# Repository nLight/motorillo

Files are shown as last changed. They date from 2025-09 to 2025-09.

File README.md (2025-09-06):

# Motorillo 🎬

> **Precision stepper motor controller with WebUSB interface for camera sliders, timelapses, and automation projects.**





## ✨ Features

- 🌐 **Browser Control**: Direct WebUSB communication - no drivers needed
- 📱 **Dual Interface**: Standalone OLED menu + web interface
- 💾 **Persistent Storage**: Save up to 5 programs in EEPROM
- ⚡ **Precision Control**: Customizable speed (1ms to 4.3M ms per step)
- 🔄 **Auto-Recovery**: Graceful USB disconnection handling
- 🎯 **Infinite Programs**: Forward/backward motion until manually stopped
- 📊 **Real-time Feedback**: Live position and status updates

## 🚀 Quick Start

### Hardware Requirements

| Component | Specification |
| --- | --- |
| **Arduino Board**  | Leonardo/Micro/Zero (WebUSB compatible) |
| **Stepper Motor**  | 200 steps/revolution with compatible driver |
| **Driver** | A4988, TMC2209 |
| **Display** | SSD1306 OLED 96×16 pixels (I2C) |
| **Control Button** | Momentary push button |

### Connections

```
Arduino Leonardo/Micro:
├── Pin 10 → Stepper DIR
├── Pin 16 → Stepper STEP
├── Pin 2  → Control Button (internal pullup)
├── SDA/SCL → OLED Display (I2C)
└── USB → Computer (WebUSB + Power)
```

### Installation

1. **Clone the repository:**

   ```bash
   git clone https://github.com/yourusername/motorillo.git
   cd motorillo
   ```

2. **Upload firmware:**

   - Open `steppper.ino` in Arduino IDE
   - Install required libraries (see [Setup Guide](docs/setup/installation.md))
   - Upload to your Arduino board

3. **Access web interface:**
   - Serve the `webusb/` folder on localhost
   - Connect via Chrome/Edge browser
   - Click "Connect Slider" to establish WebUSB connection

## 📖 Documentation

- 📋 **[Setup Guide](docs/setup/)** - Hardware assembly and software installation
- 🛠 **[User Manual](docs/features/)** - Operating modes and program creation
- 👨‍💻 **[Development](docs/development/)** - Architecture and API reference
- 🔧 **[Troubleshooting](docs/setup/troubleshooting.md)** - Common issues and solutions

## 💡 Use Cases

- **📹 Camera Sliders**: Smooth motion for video production
- **⏱ Timelapse Photography**: Ultra-slow motion over hours/days
- **🏭 Automation**: Precise positioning for manufacturing
- **🎓 Education**: Learn motor control and WebUSB programming
- **🔬 Research**: Laboratory positioning systems

## 🎮 Control Modes

### Standalone Mode (OLED + Button)

- Navigate stored programs with push button
- View current position and status
- Start/stop/pause program execution

### WebUSB Mode (Browser Interface)

- Create and save motion programs
- Manual jog controls with custom speed
- Real-time monitoring and control
- Bulk program management

## 🔧 Technical Specifications

| Parameter | Range | Default |
| --- | --- | --- |
| **Speed Range** | 1ms - 4,294,967,295ms per step  | 1000ms |
| **Max Programs** | 5 stored programs | - |
| **Position Range** | 0 - 65,535 steps | 2000 steps |
| **Loop Programs**  | Infinite until manually stopped | - |
| **Memory Usage** | ~1KB EEPROM | - |

## 🏗 Architecture

```
┌─────────────────┐    ┌──────────────────┐
│   Web Browser   │◄──►│   Pro Micro      │
│   (WebUSB UI)   │    │   (Motorillo)    │
└─────────────────┘    └──────────────────┘
                                │
                        ┌───────┴───────┐
                        │ Stepper Motor │
                        │   + Driver    │
                        └───────────────┘
```

**Modular Firmware:**

- `motor_control` - Movement and positioning
- `command_processor` - WebUSB communication
- `config_manager` - EEPROM storage
- `display_manager` - OLED interface
- `menu_system` - Standalone navigation

## 🤝 Contributing

We welcome contributions! Please see our [Development Guide](docs/development/) for:

- Code architecture overview
- Building and testing procedures
- Pull request guidelines

## 📚 Complete Documentation

This README provides a quick overview. For comprehensive documentation:

- **[Setup & Installation](docs/setup/)** - Hardware wiring, software installation, troubleshooting
- **[Features & Usage](docs/features/)** - User manual, speed control, WebUSB features
- **[Development](docs/development/)** - Architecture, API reference, protocol details

Start with the [Documentation Index](docs/README.md) for easy navigation.

## 📄 License

This project is licensed under the MIT License - see the [LICENSE](LICENSE) file for details.

## 🙏 Acknowledgments

- Built with Arduino framework and WebUSB standard
- OLED support via Adafruit libraries
- Inspired by the maker community's creativity

---

**Ready to automate your motion?** [Get started with the setup guide](docs/setup/) →

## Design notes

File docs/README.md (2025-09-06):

# Motorillo Documentation

Welcome to the comprehensive documentation for Motorillo, the precision stepper motor controller with WebUSB interface.

## 📖 Documentation Structure

### 🚀 Setup & Installation

Get Motorillo up and running on your system.

- **[Installation Guide](setup/installation.md)** - Complete setup from hardware to software
- **[Troubleshooting Guide](setup/troubleshooting.md)** - Common issues and solutions

### ✨ Features & Usage

Learn how to use all of Motorillo's capabilities.

- **[User Manual](features/user-manual.md)** - Complete operating guide for all users
- **[Manual Velocity Control](features/manual-velocity-control.md)** - Custom speed control system
- **[WebUSB Connection Management](features/webusb-connection.md)** - Connection handling and recovery
- **[Home Positioning System](features/home-positioning.md)** - Reference point management
- **[Extended Speed Range](features/extended-speed-range.md)** - Millisecond precision timing

### 👨‍💻 Development & Technical

Technical documentation for developers and advanced users.

- **[Architecture Overview](development/architecture.md)** - System design and module organization
- **[Command Protocol](development/command-protocol.md)** - Simplified WebUSB protocol design
- **[API Reference](development/api-reference.md)** - Complete WebUSB command reference

## 🎯 Quick Navigation

### New Users

1. Start with the **[Installation Guide](setup/installation.md)** to set up hardware and software
2. Read the **[User Manual](features/user-manual.md)** to learn basic operations
3. Check **[Troubleshooting](setup/troubleshooting.md)** if you encounter issues

### Existing Users

- **[Features Documentation](features/)** - Learn about specific capabilities
- **[API Reference](development/api-reference.md)** - WebUSB command protocol details
- **[Troubleshooting](setup/troubleshooting.md)** - Solutions to common problems

### Developers

1. **[Architecture](development/architecture.md)** - Understand the system design
2. **[Command Protocol](development/command-protocol.md)** - WebUSB communication protocol
3. **[API Reference](development/api-reference.md)** - Complete command reference

## 📋 Feature Overview

### Core Capabilities

- 🌐 **Browser Control**: Direct WebUSB communication - no drivers needed
- 📱 **Dual Interface**: Standalone OLED menu + web interface
- 💾 **Persistent Storage**: Save up to 5 programs in Arduino EEPROM
- ⚡ **Precision Control**: 1ms to 49+ days per step timing range
- 🔄 **Auto-Recovery**: Graceful USB disconnection handling

### Applications

- **📹 Camera Sliders**: Smooth motion for video production
- **⏱ Timelapse Photography**: Ultra-slow motion over hours/days
- **🏭 Automation**: Precise positioning for manufacturing
- **🎓 Education**: Learn motor control and WebUSB programming
- **🔬 Research**: Laboratory positioning systems

## 🛠 Technical Specifications

| Parameter | Range | Notes |
| --- | --- | --- |
| **Speed Range** | 1ms - 4.3B ms per step | ~49.7 days maximum |
| **Position Range** | 0 - 65,535 steps | 16-bit resolution |
| **Programs** | 5 stored programs | Persistent in EEPROM |
| **Cycle Count** | 1 - 255 cycles | For loop programs |
| **WebUSB** | Chrome/Edge browsers | No driver installation |

## 🔗 External Resources

- **[Arduino WebUSB Library](https://github.com/webusb/arduino)** - WebUSB implementation
- **[Adafruit SSD1306](https://github.com/adafruit/Adafruit_SSD1306)** - OLED display library
- **[WebUSB Specification](https://webusb.github.io/webusb/)** - WebUSB standard documentation

## 🤝 Contributing

We welcome contributions to both code and documentation!

**For Documentation**:

- Clear, concise writing
- Practical examples and use cases
- Screenshots and diagrams where helpful
- Cross-references between related topics

**For Code**:

- Follow existing code style and patterns
- Add documentation for new features
- Test thoroughly on Arduino hardware
- Consider memory constraints (Arduino Uno: 32KB flash, 2KB RAM)

## 📄 License

This documentation is part of the Motorillo project, licensed under the MIT License. See the main [LICENSE](../LICENSE) file for details.

---

**Need Help?** Start with the [Installation Guide](setup/installation.md) or check [Troubleshooting](setup/troubleshooting.md) for common issues.

**Ready to Develop?** Begin with the [Architecture Overview](development/architecture.md) to understand the system design.

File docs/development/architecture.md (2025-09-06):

# Motorillo Architecture Overview

This document provides a comprehensive overview of Motorillo's software architecture, design patterns, and module organization.

## System Architecture

### High-Level Design

```
┌─────────────────────────────────────────────────────────────┐
│                    USER INTERFACES                          │
├──────────────────┬──────────────────────────────────────────┤
│   Web Browser    │            OLED + Button                 │
│   (WebUSB Mode)  │         (Standalone Mode)                │
├──────────────────┴──────────────────────────────────────────┤
│                 COMMUNICATION LAYER                         │
├─────────────────────────────────────────────────────────────┤
│                 COMMAND PROCESSOR                           │
├─────────────────────────────────────────────────────────────┤
│                    CORE MODULES                             │
├─────────┬─────────┬─────────┬─────────┬───────────────────────┤
│ Motor   │ Display │  Menu   │ Config  │      EEPROM          │
│ Control │ Manager │ System  │ Manager │     Storage          │
└─────────┴─────────┴─────────┴─────────┴───────────────────────┘
```

### Modular Design Principles

**Separation of Concerns**: Each module handles a specific aspect of functionality

- **Motor Control**: Step generation, positioning, movement timing
- **Display Management**: OLED output, status display, menu rendering
- **Menu System**: Navigation, user interaction, program selection
- **Configuration**: Settings storage, EEPROM management, data persistence
- **Communication**: WebUSB protocol, command parsing, response handling

**Loose Coupling**: Modules communicate through well-defined interfaces

- Clear function signatures with minimal dependencies
- Event-driven communication where appropriate
- Shared state management through controlled interfaces

## Core Modules

### Motor Control (`src/motor_control.h/cpp`)

**Responsibilities**:

- Stepper motor step generation
- Position tracking and management
- Speed control and timing
- Movement execution and coordination

**Key Functions**:

```cpp
void setupMotorPins();                           // Initialize hardware pins
void moveToPositionWithSpeed(uint16_t pos, uint32_t speedMs);
void executeStoredProgram();                     // Run saved motion sequences
void updateMotorStatus();                        // Position tracking
```

**State Management**:

```cpp
extern long currentPosition;      // Current motor position
extern bool programRunning;       // Program execution state
extern bool programPaused;        // Pause state
```

**Design Patterns**:

- **State Machine**: Program execution states (stopped/running/paused)
- **Command Pattern**: Movement commands with parameters
- **Template Method**: Common movement logic with variable timing

### Display Manager (`src/display_manager.h/cpp`)

**Responsibilities**:

- OLED display initialization and control
- Status information rendering
- Menu display formatting
- Message display with timing

**Key Functions**:

```cpp
void setupDisplay();                             // Hardware initialization
void updateDisplay();                           // Refresh display content
void displayMessage(const char* msg, int duration);
void displayMenuItems(int selectedIndex);       // Menu rendering
```

**Display States**:

```cpp
extern unsigned long lastDisplayUpdate;         // Update timing
extern const unsigned long DISPLAY_UPDATE_INTERVAL;
```

**Design Patterns**:

- **Observer Pattern**: Display updates based on state changes
- **Composite Pattern**: Complex display layouts from simple elements
- **Strategy Pattern**: Different display modes (menu/status/message)

### Menu System (`src/menu_system.h/cpp`)

**Responsibilities**:

- Button input handling and debouncing
- Menu navigation logic
- Program selection and execution
- Mode switching (menu ↔ program execution)

**Key Functions**:

```cpp
void setupButton();                             // Input initialization
void checkButton();                            // Input processing with debouncing
void buildMenuItems();                         // Dynamic menu construction
void enterMenuMode();                          // Mode switching
void exitMenuMode();
```

**State Variables**:

```cpp
extern bool inMenuMode;                        // Current interface mode
extern int selectedMenuItem;                   // Navigation state
extern unsigned long lastButtonPress;         // Debouncing timing
```

**Design Patterns**:

- **State Machine**: Menu navigation states
- **Command Pattern**: Menu actions trigger operations
- **Builder Pattern**: Dynamic menu construction based on stored programs

### Configuration Manager (`src/config_manager.h/cpp`)

**Responsibilities**:

- EEPROM data organization and access
- Program storage and retrieval (loop and complex programs)
- Configuration persistence
- Data validation and integrity

**Key Functions**:

```cpp
void loadConfig();                             // System settings
void saveConfig();
bool loadLoopProgram(uint8_t id, LoopProgram* prog);
bool saveLoopProgram(uint8_t id, const LoopProgram* prog);
void loadProgramName(uint8_t id, char* name);
uint8_t getProgramType(uint8_t id);           // Program type detection
```

**Data Structures**:

```cpp
struct LoopProgram {
  uint16_t steps;     // Steps per direction
  uint32_t delayMs;   // Delay between steps
  uint8_t cycles;     // Number of cycles
};

struct ComplexProgram {
  uint8_t stepCount;
  struct {
    uint16_t position;
    uint32_t speedMs;
    uint16_t pauseMs;
  } steps[MAX_COMPLEX_STEPS];
};
```

**Design Patterns**:

- **Repository Pattern**: Abstract EEPROM access
- **Factory Pattern**: Program creation based on type
- **Memento Pattern**: State persistence and restoration

### Command Processor (`src/command_processor.h/cpp`)

**Responsibilities**:

- WebUSB communication protocol handling
- Binary command parsing and validation
- Response generation and transmission
- Error handling and logging

**Key Functions**:

```cpp
void processCommandCode(uint8_t cmdCode, char* data, int dataLen);
void sendProgramData();                        // Bulk data transmission
void handleConfigCommand(const uint8_t* data); // Configuration updates
void handleProgramCommand(const uint8_t* data); // Program management
```

**Protocol Design**:

```cpp
// Command structure
enum CommandCodes {
  CMD_CONFIG = 1,           // System configuration
  CMD_POS_WITH_SPEED = 15,  // Position movement
  CMD_LOOP_PROGRAM = 9,     // Simple programs
  CMD_PROGRAM = 10,         // Complex programs
  CMD_GET_ALL_DATA = 13,    // Data synchronization
  CMD_DEBUG_INFO = 14       // Connection health
};
```

**Design Patterns**:

- **Command Pattern**: Each command encapsulates operation
- **Strategy Pattern**: Different parsing strategies for command types
- **Chain of Responsibility**: Command processing pipeline

## Communication Architecture

### WebUSB Protocol Design

**Binary Format Benefits**:

- Memory efficiency (crucial for Arduino constraints)
- Fast parsing (no string manipulation overhead)
- Type safety (fixed-size fields prevent errors)
- Cross-platform compatibility (little-endian encoding)

**Protocol Stack**:

```
Application Layer  │ Movement Commands, Program Data
─────────────────  ├─────────────────────────────────
Transport Layer    │ Binary Protocol, Command Codes
─────────────────  ├─────────────────────────────────
Physical Layer     │ WebUSB, Arduino USB Stack
```

**Data Flow**:

```
Browser JavaScript ──[Binary Commands]──→ Arduino
                  ←──[Status/Data]───────
```

### Connection Management

**State Machine**:

```
┌─────────────┐    WebUSB Available    ┌──────────────────┐
│ Standalone  │ ───────────────────→   │ Programming Mode │
│    Mode     │ ←─────────────────────  │                  │
└─────────────┘    Connection Lost     └──────────────────┘
```

**Disconnection Detection**:

- **Arduino Side**: Timeout-based detection (3 seconds)
- **Browser Side**: Event-driven + ping-based health monitoring
- **Recovery**: Automatic fallback to standalone mode

## Memory Management

### EEPROM Organization

```
Address Range  │ Content              │ Size    │ Notes
───────────────┼──────────────────────┼─────────┼──────────────────
0x000 - 0x007  │ Configuration        │ 8 bytes │ System settings
0x008 - 0x027  │ Program Names        │ 32 bytes│ 8 chars × 4 programs
0x028 - 0x067  │ Loop Programs        │ 64 bytes│ 16 bytes × 4 programs
0x068 - 0x1FF  │ Complex Programs     │ 408 bytes│ Variable length
0x200 - 0x3FF  │ Reserved/Future      │ 512 bytes│ Expansion space
```

**Memory Constraints**:

- Arduino Uno: 1024 bytes EEPROM total
- Memory-optimized string handling (no String class)
- F() macro for flash storage of constants
- Aggressive removal of debug messages in production

### RAM Optimization

**Techniques Used**:

```cpp
// Flash string storage
const char* const messages[] PROGMEM = {
  "Program Running",
  "Position: ",
  "Speed: "
};

// Minimal buffer sizes
char nameBuffer[9];  // Exactly sized for 8-char names + null

// Avoid String class overhead
void appendInt(char* buffer, int value) {
  // Manual integer to string conversion
}
```

## Design Patterns Implementation

### State Machine Pattern

**Menu Navigation**:

```cpp
enum MenuState {
  MENU_BROWSE,     // Scrolling through programs
  MENU_EXECUTE,    // Running selected program
  MENU_PAUSED      // Program paused
};

void handleMenuState(MenuState state, ButtonEvent event) {
  switch(state) {
    case MENU_BROWSE:
      if(event == BUTTON_PRESS) enterExecuteMode();
      break;
    case MENU_EXECUTE:
      if(event == BUTTON_PRESS) pauseProgram();
      break;
    // ...
  }
}
```

### Command Pattern

**Movement Commands**:

```cpp
class MovementCommand {
  uint16_t targetPosition;
  uint32_t speedMs;

  void execute() {
    moveToPositionWithSpeed(targetPosition, speedMs);
  }
};
```

### Observer Pattern

**Status Updates**:

```cpp
void notifyPositionChange(long newPosition) {
  currentPosition = newPosition;
  updateDisplay();        // Observer 1: Display
  sendPositionUpdate();   // Observer 2: WebUSB client
}
```

## Error Handling Strategy

### Graceful Degradation

**Connection Loss**:

- WebUSB disconnection → Continue in standalone mode
- Display failure → Continue with basic operation
- EEPROM corruption → Use default values

**Input Validation**:

```cpp
bool validateSpeed(uint32_t speedMs) {
  if(speedMs < 1 || speedMs > MAX_SPEED_MS) {
    displayMessage("Invalid Speed", 2000);
    return false;
  }
  return true;
}
```

### Resource Management

**Memory Safety**:

- Bounds checking on all array access
- EEPROM address validation
- Buffer overflow prevention

**Hardware Safety**:

- Speed limiting to prevent mechanical damage
- Position bounds checking
- Thermal protection considerations

This architecture provides a robust, maintainable foundation for Motorillo's diverse functionality while respecting Arduino's resource constraints.

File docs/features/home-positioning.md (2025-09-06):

# Home Positioning System

This document describes Motorillo's flexible home positioning system, providing both physical homing and reference point setting capabilities.

## Overview

Motorillo provides two complementary approaches to home positioning:

- **Physical Homing**: Move the motor to position 0 with controllable speed
- **Reference Setting**: Set current position as home without movement

This dual approach accommodates different workflows and use cases, from automatic calibration to manual setup scenarios.

## Home Positioning Options

### Set Home (Current Position)

**Purpose**: Establish a new reference point without motor movement

**Usage**:

- After manually positioning the slider to desired starting location
- When recalibrating after power cycling
- Setting custom reference points for specific projects

**Command**: `SETHOME` (standalone) or via green "Set Home" button (WebUSB)

**Behavior**:

- Updates software position counter to zero
- No physical motor movement
- Immediate operation
- Displays "Set Home" confirmation on OLED

### Go to Home (Position 0)

**Purpose**: Physically move motor to the zero position with controlled speed

**Usage**:

- Returning to known reference position
- Automatic calibration sequences
- Preparing for program execution

**Command**: `HOME` or `CMD_POS_WITH_SPEED` with position=0 (WebUSB)

**Behavior**:

- Physical movement to position 0
- Uses current manual speed setting (WebUSB mode)
- Respects speed and acceleration settings
- Shows movement progress on display

## WebUSB Interface

### Visual Interface Design

```html
<!-- Green button for reference setting -->
<button id="setHomeBtn" class="btn btn-success">
  Set Home (Current Position)
</button>

<!-- Orange button for physical movement -->
<button id="goHomeBtn" class="btn btn-warning">Go to Home (Position 0)</button>
```

### Implementation

```javascript
handleSetHome() {
  // Set current position as home without movement
  this.sendCommand(this.CMD_SETHOME, new Uint8Array([]));
  this.log("Setting current position as home (no movement)");
}

handleGoHome() {
  // Move to position 0 with current speed setting
  const speed = parseInt(document.getElementById("manualSpeed").value);
  const buffer = new ArrayBuffer(6);
  const view = new DataView(buffer);
  view.setUint16(0, 0, true);      // Position = 0 (home)
  view.setUint32(2, speed, true);  // User-defined speed

  this.sendCommand(this.CMD_POS_WITH_SPEED, new Uint8Array(buffer));
  this.log(`Moving to home position (0) at ${speed}ms per step`);
}
```

## Arduino Implementation

### Set Home Command

```cpp
case CMD_SETHOME: {
  currentPosition = 0;  // Reset position counter
  displayMessage(F("Set Home"), 2000);
  break;
}
```

### Physical Home Movement

```cpp
case CMD_POS_WITH_SPEED: {
  uint16_t targetPosition = *(uint16_t *)data;
  uint32_t speedMs = *(uint32_t *)(data + 2);

  if (targetPosition == 0) {
    // This is a home operation - move to position 0
    moveToPositionWithSpeed(0, speedMs);
  } else {
    // Regular position movement
    moveToPositionWithSpeed(targetPosition, speedMs);
  }
  break;
}
```

## Use Cases

### Manual Setup Workflow

1. **Physical Positioning**: Manually move slider to desired starting position
2. **Set Reference**: Use "Set Home (Current Position)" to establish reference
3. **Begin Work**: Start timelapse or motion sequence from this position

### Automatic Calibration

1. **Power On**: Arduino boots with unknown position
2. **Go to Home**: Use "Go to Home (Position 0)" to move to known reference
3. **Ready State**: Now at calibrated zero position for accurate movements

### Project-Specific References

1. **Scene Setup**: Position camera/subject for specific shot
2. **Mark Position**: Set current position as home for this project
3. **Motion Programming**: Create programs relative to this reference point

### Recovery Scenarios

1. **Power Loss**: After power cycling, position may be unknown
2. **Manual Movement**: If slider was manually moved during transport
3. **Reference Reset**: Quick way to establish new reference without complex calibration

## Benefits

### Flexibility

- **No Movement Required**: Set home instantly without waiting for motor movement
- **Speed Control**: Physical homing respects user speed preferences
- **Multiple References**: Can set different home positions for different projects
- **Fast Setup**: Quick reference establishment for rapid workflow

### Safety

- **Position Awareness**: Clear distinction between movement and reference operations
- **Visual Feedback**: Different colored buttons prevent user confusion
- **Controlled Movement**: Physical homing uses safe, user-defined speeds
- **Immediate Feedback**: OLED display confirms all home operations

### Workflow Integration

- **Project Setup**: Establish references that make sense for each specific project
- **Equipment Transport**: Re-establish references after moving equipment
- **Calibration**: Support both manual and automatic calibration workflows
- **Recovery**: Quick recovery from power loss or manual positioning

## Advanced Usage

### Timelapse Setup

```javascript
// 1. Manually position for perfect framing
// 2. Set as home reference
handleSetHome();

// 3. Create timelapse program starting from this reference
const program = {
  name: "SUNSET",
  startPos: 0, // Start from home reference
  endPos: 2000, // End position
  duration: 7200000, // 2 hours total
};
```

### Multi-Point Calibration

```javascript
// Set multiple reference points for complex sequences
// Home = starting position
handleSetHome();

// Create program with multiple waypoints relative to home
const waypoints = [
  { pos: 0, speed: 1000 }, // Start at home
  { pos: 500, speed: 2000 }, // Slow to first waypoint
  { pos: 1500, speed: 1000 }, // Normal to second waypoint
  { pos: 0, speed: 500 }, // Slow return to home
];
```

This flexible home positioning system makes Motorillo adaptable to a wide variety of workflows, from simple timelapse setups to complex multi-position cinematography sequences.

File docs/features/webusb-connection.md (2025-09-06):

# WebUSB Connection Management

This document describes Motorillo's robust WebUSB connection management, including automatic disconnection detection and seamless mode switching.

## Overview

Motorillo implements intelligent connection management that provides:

- **Automatic Detection**: Seamless switching between WebUSB and standalone modes
- **Disconnection Handling**: Graceful recovery when USB connection is lost
- **Dual Operation**: Continues functioning even without browser connection
- **Fast Recovery**: Quick detection and response to connection changes

## Connection Architecture

### Dual-Mode Operation

```
┌─────────────────┐    ┌──────────────────┐
│   Web Browser   │◄──►│   Arduino Board  │
│  (WebUSB Mode)  │    │   (Motorillo)    │
└─────────────────┘    └──────────────────┘
                                │
                        ┌───────┴───────┐
                        │ OLED Display   │
                        │ (Standalone)   │
                        └───────────────┘
```

**WebUSB Mode**: Full browser control with web interface
**Standalone Mode**: OLED menu navigation with physical button

## Arduino Firmware Implementation

### Connection Variables

```cpp
unsigned long lastWebUSBActivity = 0;
const unsigned long webUSBTimeoutMs = 3000; // 3 seconds timeout
bool wasInProgrammingMode = false;
bool programmingMode = false;
```

### Detection Logic

```cpp
// Update activity timestamp when data received
if (programmingMode && Serial && Serial.available()) {
  lastWebUSBActivity = millis();
  // Process WebUSB commands...
}

// Check for disconnection timeout
if (programmingMode && serialCheckComplete) {
  if (millis() - lastWebUSBActivity > webUSBTimeoutMs) {
    // Connection lost - switch to standalone mode
    programmingMode = false;
    wasInProgrammingMode = false;

    // Automatically enter menu mode
    if (!inMenuMode) {
      enterMenuMode();
    }
    updateDisplay();
  }
}
```

### Connection Establishment

```cpp
// Detect WebUSB connection during boot
if (!serialCheckComplete) {
  if (Serial && (millis() - bootTime < serialWaitTime)) {
    if (!programmingMode) {
      programmingMode = true;
      Serial.println("WebUSB Connected");
      sendAllEEPROMData(); // Send stored programs
    }
  }
}

// Handle reconnection during operation
if (serialCheckComplete && !programmingMode && Serial) {
  programmingMode = true;
  wasInProgrammingMode = true;
  lastWebUSBActivity = millis();

  // Exit menu mode when switching to programming
  if (inMenuMode) {
    exitMenuMode();
  }

  Serial.println("WebUSB Connected");
  sendAllEEPROMData();
}
```

## JavaScript Client Implementation

### Connection Health Monitoring

```javascript
class SliderController {
  constructor() {
    this.pingInterval = null;
    this.connectionHealthy = true;
  }

  async connect() {
    try {
      // Establish WebUSB connection
      this.port = await serial.requestPort();
      await this.port.connect();

      // Set up error handlers
      this.port.onReceiveError = (error) => {
        this.handleDisconnection("Receive error: " + error.message);
      };

      // Start connection health monitoring
      this.startPing();
    } catch (error) {
      this.handleDisconnection("Connection failed: " + error.message);
    }
  }

  startPing() {
    this.pingInterval = setInterval(() => {
      if (this.connectionHealthy) {
        try {
          // Send ping command to check connection
          this.sendCommand(this.CMD_DEBUG_INFO, new Uint8Array([]));
        } catch (error) {
          this.handleDisconnection("Ping failed: " + error.message);
        }
      }
    }, 2000); // Ping every 2 seconds
  }
}
```

### Disconnection Handling

```javascript
handleDisconnection(reason) {
  console.log(`WebUSB disconnected: ${reason}`);

  // Clear health monitoring
  if (this.pingInterval) {
    clearInterval(this.pingInterval);
    this.pingInterval = null;
  }

  this.connectionHealthy = false;
  this.port = null;

  // Update UI to reflect disconnected state
  document.getElementById("connectBtn").textContent = "Connect Slider";
  document.getElementById("connectBtn").disabled = false;

  // Show disconnection message
  this.log(`Connection lost: ${reason}`, 'error');
}
```

## Connection Flow

### Initial Connection

1. **Browser Request**: User clicks "Connect Slider" button
2. **Device Selection**: Browser shows available Arduino devices
3. **USB Handshake**: WebUSB protocol establishes connection
4. **Mode Switch**: Arduino detects connection and enters programming mode
5. **Data Sync**: Arduino sends all stored programs to browser
6. **Health Monitoring**: JavaScript starts ping monitoring

### Normal Operation

1. **Command Sending**: Browser sends movement/program commands
2. **Activity Tracking**: Arduino updates `lastWebUSBActivity` timestamp
3. **Response Processing**: Browser receives and processes responses
4. **Continuous Ping**: JavaScript sends periodic health checks

### Disconnection Detection

**Arduino Side (Timeout-based):**

1. No data received for 3+ seconds
2. Automatic switch to standalone mode
3. Enter OLED menu for continued operation

**JavaScript Side (Event-based):**

1. USB disconnect event detected
2. Send error during ping or command
3. Clear intervals and update UI
4. Show reconnection option

### Reconnection

1. **Manual Reconnect**: User clicks "Connect Slider" again
2. **Automatic Detection**: Arduino detects new connection
3. **Mode Switch**: Exit standalone mode, enter programming mode
4. **Data Resync**: Send all current program data to browser

## Benefits

### Reliability Features

1. **Fast Detection**: 3-second timeout ensures quick response
2. **Dual Detection**: Both Arduino and browser detect disconnections
3. **Automatic Recovery**: Arduino continues operating without browser
4. **Seamless Switching**: Smooth transitions between connection states

### User Experience

1. **No Data Loss**: Programs stored in Arduino EEPROM persist
2. **Continued Operation**: OLED interface always available
3. **Clear Status**: Connection state clearly displayed
4. **Easy Reconnection**: Single click to restore WebUSB connection

### Robustness

1. **Error Handling**: Comprehensive error detection and logging
2. **Resource Cleanup**: Proper cleanup of intervals and connections
3. **State Consistency**: Connection state kept synchronized
4. **Graceful Degradation**: Reduced functionality rather than failure

## Troubleshooting

### Connection Issues

**Symptom**: Can't establish initial connection
**Solution**:

- Ensure Arduino has WebUSB-compatible firmware
- Use Chrome/Edge browser (WebUSB support required)
- Check USB cable and port

**Symptom**: Frequent disconnections
**Solution**:

- Check USB cable quality
- Reduce ping interval if needed
- Verify power supply stability

**Symptom**: Arduino doesn't switch modes
**Solution**:

- Check serial monitor for debug messages
- Verify timeout settings in firmware
- Ensure WebUSB library is properly included

### Debug Commands

- **CMD_DEBUG_INFO (14)**: Responds with "PONG" for connection testing
- **Serial Monitor**: Shows connection status and timeout events
- **Browser Console**: Displays connection errors and ping responses

This comprehensive connection management ensures Motorillo provides a robust, user-friendly experience whether used via browser control or standalone operation.

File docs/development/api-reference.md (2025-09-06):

# Motorillo API Reference

This document provides a comprehensive reference for Motorillo's WebUSB command protocol and programming interface.

## WebUSB Command Protocol

### Overview

Motorillo uses a binary protocol for efficient communication between the browser and Arduino. All multi-byte values use little-endian encoding for cross-platform compatibility.

### Command Format

```
[Command Code: uint8][Parameters: variable length]
```

## Core Commands

### System Configuration

#### CMD_CONFIG (1)

Configure system parameters and defaults.

**Format**: 9 bytes total

```
[1][totalSteps: uint16][speed: uint32][acceleration: uint8][microstepping: uint8]
```

**Parameters**:

- `totalSteps`: Maximum travel distance (0-65535 steps)
- `speed`: Default movement speed (1-4294967295 milliseconds per step)
- `acceleration`: Acceleration profile (1-255, higher = smoother)
- `microstepping`: Driver microstepping mode (1, 2, 4, 8, 16)

**Example**:

```javascript
const config = new ArrayBuffer(9);
const view = new DataView(config);
view.setUint8(0, 1); // Command code
view.setUint16(1, 2000, true); // 2000 steps total
view.setUint32(3, 1000, true); // 1000ms default speed
view.setUint8(7, 50); // Acceleration
view.setUint8(8, 1); // Full steps
```

### Movement Commands

#### CMD_POS_WITH_SPEED (15)

Move to specific position with custom speed.

**Format**: 6 bytes total

```
[15][position: uint16][speed: uint32]
```

**Parameters**:

- `position`: Target position (0-65535 steps)
- `speed`: Movement speed (1-4294967295 milliseconds per step)

**Example**:

```javascript
// Move to position 1500 at 2000ms per step
const moveCmd = new ArrayBuffer(6);
const view = new DataView(moveCmd);
view.setUint8(0, 15); // Command code
view.setUint16(1, 1500, true); // Target position
view.setUint32(3, 2000, true); // Speed (2 seconds per step)
```

**Special Cases**:

- Position 0 = Home operation
- Use current manual speed setting for consistent behavior

### Program Management

#### CMD_LOOP_PROGRAM (9)

Create or update simple back-and-forth programs.

**Format**: 17 bytes total

```
[9][programId: uint8][name: 8 chars][steps: uint16][delayMs: uint32][cycles: uint8]
```

**Parameters**:

- `programId`: Program slot (0-4)
- `name`: Program name (8 ASCII characters, space-padded)
- `steps`: Steps per direction (1-32767)
- `delayMs`: Delay between steps (1-4294967295 milliseconds)
- `cycles`: Number of forward/backward cycles (1-255)

**Example**:

```javascript
// Create timelapse program
const program = new ArrayBuffer(17);
const view = new DataView(program);
view.setUint8(0, 9); // Command code
view.setUint8(1, 0); // Program slot 0

// Program name (8 chars, space-padded)
const name = "TIMELAPS";
for (let i = 0; i < 8; i++) {
  view.setUint8(2 + i, name.charCodeAt(i) || 32);
}

view.setUint16(10, 1000, true); // 1000 steps per direction
view.setUint32(12, 30000, true); // 30 seconds between steps
view.setUint8(16, 1); // 1 cycle (forward + back)
```

#### CMD_PROGRAM (10)

Create complex multi-waypoint programs.

**Format**: Variable length

```
[10][programId: uint8][name: 8 chars][stepCount: uint8]
[position1: uint16][speed1: uint32][pause1: uint16]
[position2: uint16][speed2: uint32][pause2: uint16]
...
```

**Parameters**:

- `programId`: Program slot (0-4)
- `name`: Program name (8 ASCII characters, space-padded)
- `stepCount`: Number of waypoints (1-20)
- For each step:
  - `position`: Target position (0-65535 steps)
  - `speed`: Movement speed (1-4294967295 milliseconds per step)
  - `pause`: Pause at position (0-65535 milliseconds)

**Example**:

```javascript
// 3-waypoint cinematic sequence
const program = new ArrayBuffer(11 + 3 * 8); // Header + 3 steps
const view = new DataView(program);
view.setUint8(0, 10); // Command code
view.setUint8(1, 1); // Program slot 1

// Program name
const name = "CINEMATIC";
for (let i = 0; i < 8; i++) {
  view.setUint8(2 + i, name.charCodeAt(i) || 32);
}

view.setUint8(10, 3); // 3 waypoints

// Waypoint 1: Slow start
let offset = 11;
view.setUint16(offset, 0, true); // Position 0
view.setUint32(offset + 2, 3000, true); // 3 seconds per step
view.setUint16(offset + 6, 2000, true); // 2 second pause

// Waypoint 2: Normal speed
offset += 8;
view.setUint16(offset, 1000, true); // Position 1000
view.setUint32(offset + 2, 1000, true); // 1 second per step
view.setUint16(offset + 6, 1000, true); // 1 second pause

// Waypoint 3: Slow end
offset += 8;
view.setUint16(offset, 2000, true); // Position 2000
view.setUint32(offset + 2, 5000, true); // 5 seconds per step
view.setUint16(offset + 6, 0, true); // No final pause
```

### Program Control

#### CMD_RUN (3)

Execute stored program by ID.

**Format**: 2 bytes total

```
[3][programId: uint8]
```

**Example**:

```javascript
// Run program in slot 0
const runCmd = new ArrayBuffer(2);
const view = new DataView(runCmd);
view.setUint8(0, 3); // Command code
view.setUint8(1, 0); // Program ID
```

#### CMD_START (4)

Start program execution.

**Format**: 1 byte

```
[4]
```

#### CMD_STOP (5)

Stop program execution.

**Format**: 1 byte

```
[5]
```

### Data Retrieval

#### CMD_GET_ALL_DATA (13)

Request all stored configuration and programs.

**Format**: 1 byte

```
[13]
```

**Response**: Text format for reliability

```
PROGRAMS:n
PROG:id,name,steps,delay,cycles
PROG:id,name,steps,delay,cycles
...
```

**Example Response**:

```
PROGRAMS:2
PROG:0,SUNSET  ,1000,30000,1
PROG:1,PRODUCT ,72,2000,1
```

#### CMD_DEBUG_INFO (14)

Connection health check (ping).

**Format**: 1 byte

```
[14]
```

**Response**: Text "PONG" for connection verification

### Utility Commands

#### CMD_SETHOME (8)

Set current position as home reference.

**Format**: 1 byte

```
[8]
```

**Behavior**: Updates position counter to 0 without motor movement

#### CMD_GET_CONFIG (7)

Request current system configuration.

**Format**: 1 byte

```
[7]
```

## JavaScript API

### SliderController Class

```javascript
class SliderController {
  constructor() {
    this.port = null;
    this.connectionHealthy = false;

    // Command codes
    this.CMD_CONFIG = 1;
    this.CMD_POS_WITH_SPEED = 15;
    this.CMD_LOOP_PROGRAM = 9;
    this.CMD_PROGRAM = 10;
    // ... other commands
  }

  async connect() {
    // Establish WebUSB connection
  }

  disconnect() {
    // Clean disconnect and cleanup
  }

  sendCommand(cmdCode, data) {
    // Send binary command to Arduino
  }

  // High-level API methods
  async moveToPosition(position, speed) {
    const buffer = new ArrayBuffer(6);
    const view = new DataView(buffer);
    view.setUint16(0, position, true);
    view.setUint32(2, speed, true);

    return this.sendCommand(this.CMD_POS_WITH_SPEED, new Uint8Array(buffer));
  }

  async createLoopProgram(id, name, steps, delay, cycles) {
    // Implementation for loop program creation
  }

  async runProgram(programId) {
    const buffer = new ArrayBuffer(2);
    const view = new DataView(buffer);
    view.setUint8(0, programId);

    return this.sendCommand(this.CMD_RUN, new Uint8Array(buffer));
  }
}
```

### Usage Examples

#### Basic Movement

```javascript
const slider = new SliderController();
await slider.connect();

// Move to position 1000 at 1500ms per step
await slider.moveToPosition(1000, 1500);

// Go home (position 0) quickly
await slider.moveToPosition(0, 500);
```

#### Program Creation

```javascript
// Create simple timelapse
await slider.createLoopProgram(
  0, // Program ID
  "SUNSET", // Name
  1200, // Steps per direction
  45000, // 45 seconds per step
  1 // 1 cycle (forward + back)
);

// Execute the program
await slider.runProgram(0);
```

## Error Handling

### Command Validation

**Client Side**:

```javascript
function validateSpeed(speed) {
  if (speed < 1 || speed > 4294967295) {
    throw new Error(`Invalid speed: ${speed}. Must be 1-4294967295ms`);
  }
}

function validatePosition(position) {
  if (position < 0 || position > 65535) {
    throw new Error(`Invalid position: ${position}. Must be 0-65535 steps`);
  }
}
```

**Arduino Side**:

- Parameter bounds checking
- EEPROM address validation
- Memory allocation verification
- Safe defaults for invalid data

### Connection Error Handling

```javascript
try {
  await slider.sendCommand(cmdCode, data);
} catch (error) {
  if (error.name === "NetworkError") {
    // Connection lost - handle gracefully
    this.handleDisconnection(error.message);
  } else {
    // Other error - log and retry
    console.error("Command failed:", error);
  }
}
```

## Performance Considerations

### Memory Usage

- **Command Buffers**: Use ArrayBuffer for binary data
- **String Handling**: Minimize string operations
- **Batch Operations**: Combine multiple commands when possible

### Timing

- **Command Delays**: Allow time between rapid commands
- **Long Operations**: Use progress callbacks for user feedback
- **Connection Health**: Implement ping/pong for connection monitoring

### Best Practices

1. **Validate Input**: Check all parameters before sending commands
2. **Handle Errors**: Implement robust error handling and recovery
3. **User Feedback**: Provide clear status and progress information
4. **Resource Cleanup**: Properly disconnect and clean up resources
5. **Performance**: Use binary protocol for efficiency

This API reference provides the complete interface for integrating with Motorillo's WebUSB protocol.

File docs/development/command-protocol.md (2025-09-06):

# Command Protocol Simplification

This document describes the streamlined command protocol implemented in Motorillo, reducing complexity while maintaining full functionality.

## Overview

Motorillo's command protocol has been simplified to use fewer, more consistent commands. This reduces code complexity, improves maintainability, and provides a cleaner API for position control operations.

## Protocol Evolution

### Before Simplification

**Multiple Position Commands**:

- `CMD_POS (2)`: Move to position (no speed control)
- `CMD_HOME (6)`: Move to home (no speed control)
- `CMD_POS_WITH_SPEED (15)`: Move to position with speed
- `CMD_HOME_WITH_SPEED (16)`: Move to home with speed

**Problems**:

- Redundant command codes
- Inconsistent parameter formats
- Multiple code paths for similar operations
- Maintenance complexity

### After Simplification

**Unified Position Command**:

- `CMD_POS_WITH_SPEED (15)`: All position movements with speed control

**Benefits**:

- Single command for all position operations
- Consistent binary format
- Simplified code paths
- Easier maintenance

## Unified Command Format

### CMD_POS_WITH_SPEED (15)

**Binary Format**: 6 bytes total

```
[Command Code: 15][Position: uint16][Speed: uint32]
```

**Parameters**:

- **Position**: Target position (0-65535 steps)
- **Speed**: Movement speed (1-4294967295 milliseconds per step)
- **Encoding**: Little-endian byte order for cross-platform compatibility

**Usage Examples**:

```javascript
// Move to position 1000 at normal speed
const moveBuffer = new ArrayBuffer(6);
const moveView = new DataView(moveBuffer);
moveView.setUint16(0, 1000, true); // Position = 1000
moveView.setUint32(2, 1000, true); // Speed = 1000ms per step

// Home operation (move to position 0)
const homeBuffer = new ArrayBuffer(6);
const homeView = new DataView(homeBuffer);
homeView.setUint16(0, 0, true); // Position = 0 (home)
homeView.setUint32(2, 2000, true); // Speed = 2000ms per step
```

## Implementation Changes

### JavaScript (WebUSB Interface)

**Removed Legacy Commands**:

```javascript
// OLD - Multiple command codes
this.CMD_POS = 2; // Removed
this.CMD_HOME = 6; // Removed
this.CMD_HOME_WITH_SPEED = 16; // Removed

// NEW - Single command
this.CMD_POS_WITH_SPEED = 15; // Unified position command
```

**Updated Movement Functions**:

```javascript
handleMove() {
  const position = parseInt(document.getElementById("targetPosition").value);
  const speed = parseInt(document.getElementById("manualSpeed").value);

  // Create unified position command
  const buffer = new ArrayBuffer(6);
  const view = new DataView(buffer);
  view.setUint16(0, position, true);
  view.setUint32(2, speed, true);

  this.sendCommand(this.CMD_POS_WITH_SPEED, new Uint8Array(buffer));
  this.log(`Moving to position ${position} at ${speed}ms per step`);
}

handleHome() {
  const speed = parseInt(document.getElementById("manualSpeed").value);

  // Home is just position 0 with user speed
  const buffer = new ArrayBuffer(6);
  const view = new DataView(buffer);
  view.setUint16(0, 0, true);        // Position = 0 (home)
  view.setUint32(2, speed, true);    // User-defined speed

  this.sendCommand(this.CMD_POS_WITH_SPEED, new Uint8Array(buffer));
  this.log(`Going home (position 0) at ${speed}ms per step`);
}
```

### Arduino Firmware

**Removed Command Handlers**:

```cpp
// OLD - Multiple separate handlers
case CMD_POS: {
  // Legacy position command - REMOVED
  break;
}
case CMD_HOME: {
  // Legacy home command - REMOVED
  break;
}
case CMD_HOME_WITH_SPEED: {
  // Separate home with speed - REMOVED
  break;
}
```

**Unified Command Handler**:

```cpp
case CMD_POS_WITH_SPEED: {
  // Extract position and speed from binary data
  uint16_t position = *(uint16_t *)data;
  uint32_t speedMs = *(uint32_t *)(data + 2);

  // Single function handles all position movements
  moveToPositionWithSpeed(position, speedMs);

  // Special case: position 0 is home operation
  if (position == 0) {
    displayMessage(F("Going Home"), 1000);
  } else {
    displayMessage(F("Moving"), 1000);
  }

  break;
}
```

## Conceptual Benefits

### Simplified Mental Model

**Home Operation Redefined**:

- **Old Concept**: "Home" is a special operation requiring separate commands
- **New Concept**: "Home" is simply moving to position 0

This makes the system more intuitive and reduces the number of concepts users need to understand.

### Consistent Speed Control

**All Movements Have Speed Control**:

- No legacy commands without speed parameters
- User always has control over movement speed
- Consistent behavior across all operations
- Predictable timing for all movements

### Code Maintenance

**Single Code Path**:

```cpp
// Before: Multiple movement functions
void moveToPosition(uint16_t pos);
void moveHome();
void moveToPositionWithSpeed(uint16_t pos, uint32_t speed);
void moveHomeWithSpeed(uint32_t speed);

// After: Single movement function
void moveToPositionWithSpeed(uint16_t pos, uint32_t speed);
```

**Reduced Complexity**:

- 75% fewer command handlers
- Single binary format to maintain
- Consistent parameter validation
- Unified error handling

## Migration Benefits

### For Developers

1. **Fewer Commands**: Simpler API with fewer command codes to remember
2. **Consistent Format**: All position commands use same binary structure
3. **Single Code Path**: One movement function handles all cases
4. **Better Testing**: Fewer combinations to test and validate

### For Users

1. **Consistent Behavior**: All movements respect user speed settings
2. **Intuitive Home**: Home is clearly "position 0" rather than special case
3. **Speed Control**: Never stuck with fixed-speed movements
4. **Predictable Timing**: All operations use millisecond timing

### For Maintenance

1. **Less Code**: Fewer lines of code to maintain and debug
2. **Single Format**: One binary protocol to optimize and secure
3. **Unified Logic**: Same validation and error handling for all positions
4. **Cleaner Architecture**: More logical separation of concerns

## Protocol Summary

### Current Active Commands

| Command | Code | Purpose | Format |
| --- | ---- | --- | --- |
| `CMD_POS_WITH_SPEED` | 15 | All position movements | `pos(2) + speed(4)` |
| `CMD_CONFIG` | 1 | System configuration | `steps(2) + speed(4) + accel(1) + microstep(1)` |
| `CMD_LOOP_PROGRAM` | 9 | Simple back-and-forth | `id(1) + name(8) + steps(2) + delay(4) + cycles(1)` |
| `CMD_PROGRAM` | 10 | Multi-waypoint sequences | `id(1) + name(8) + count(1) + steps(var)` |

### Removed Commands

| Command | Code | Replaced By |
| --- | ---- | --- |
| `CMD_POS` | 2 | `CMD_POS_WITH_SPEED` |
| `CMD_HOME` | 6 | `CMD_POS_WITH_SPEED` (position=0) |
| `CMD_HOME_WITH_SPEED` | 16 | `CMD_POS_WITH_SPEED` (position=0) |

This simplification makes Motorillo's command protocol more intuitive, maintainable, and consistent while preserving all functionality and improving user control over movement timing.

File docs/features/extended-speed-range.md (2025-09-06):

# Extended Speed Range System

This document describes Motorillo's comprehensive speed control system, supporting everything from rapid positioning to ultra-slow timelapse motion with millisecond precision.

## Overview

Motorillo uses **milliseconds exclusively** for all timing operations, providing an extended speed range perfect for diverse applications from quick setup to professional timelapse work.

**Speed Range**: 1ms to 4,294,967,295ms per step (~49.7 days per step)

## Speed System Architecture

### Unified Timing

All operations use milliseconds for consistency:

- **Manual movements**: User-configurable speed via WebUSB interface
- **Program execution**: Per-step timing in loop and complex programs
- **Configuration**: Default speeds stored in EEPROM
- **Commands**: All speed parameters in milliseconds

### Binary Protocol Efficiency

All commands use optimized binary format for maximum performance:

```cpp
// 32-bit speed parameter (little-endian)
uint32_t speedMs = *(uint32_t *)(data + offset);
```

## Command Formats

### Configuration Command (CMD_CONFIG = 1)

**Binary Format**: 9 bytes total

```
[Command Code: 1][Total Steps: uint16][Speed: uint32][Acceleration: uint8][Microstepping: uint8]
```

**Example Configurations**:

```javascript
// Fast setup movement (1ms per step)
const fastConfig = [1, 2000, 1, 50, 1]; // 2000 steps/second

// Normal operation (1000ms per step)
const normalConfig = [1, 2000, 1000, 50, 1]; // 1 step/second

// Slow timelapse (30000ms per step)
const slowConfig = [1, 2000, 30000, 50, 1]; // 1 step per 30 seconds
```

### Position Command with Speed

**Binary Format**: 6 bytes total

```
[Command Code: 15][Position: uint16][Speed: uint32]
```

**JavaScript Implementation**:

```javascript
handleMove() {
  const position = parseInt(document.getElementById("targetPosition").value);
  const speed = parseInt(document.getElementById("manualSpeed").value);

  const buffer = new ArrayBuffer(6);
  const view = new DataView(buffer);
  view.setUint16(0, position, true);  // Little-endian position
  view.setUint32(2, speed, true);     // Little-endian speed

  this.sendCommand(this.CMD_POS_WITH_SPEED, new Uint8Array(buffer));
}
```

## Program Types

### Loop Programs

**Purpose**: Simple back-and-forth motion with consistent timing

**Binary Format**: 17 bytes total

```
[Command: 9][Program ID: uint8][Name: 8 chars][Steps: uint16][Delay: uint32][Cycles: uint8]
```

**Example**:

```javascript
// Ultra-slow sunrise timelapse
const sunriseProgram = {
  id: 0,
  name: "SUNRISE  ", // 8 characters, space-padded
  steps: 1000, // 1000 steps per direction
  delayMs: 120000, // 2 minutes between steps
  cycles: 1, // Single forward/back cycle
};

// Total duration: 1000 steps × 2 minutes × 2 directions = 66.7 hours
```

### Complex Programs

**Purpose**: Multi-waypoint sequences with variable speeds

**Binary Format**: Variable length

```
[Command: 10][Program ID: uint8][Name: 8 chars][Step Count: uint8]
[Position1: uint16][Speed1: uint32][Pause1: uint16]
[Position2: uint16][Speed2: uint32][Pause2: uint16]
...
```

**Example**:

```javascript
// Mixed-speed cinematic sequence
const cinematicProgram = {
  id: 1,
  name: "CINEMATIC",
  steps: [
    { pos: 0, speed: 5000, pause: 2000 }, // Slow start from home
    { pos: 800, speed: 1000, pause: 1000 }, // Quick to mid-position
    { pos: 2000, speed: 10000, pause: 5000 }, // Very slow to end
    { pos: 0, speed: 2000, pause: 0 }, // Medium return to home
  ],
};
```

## Practical Speed Ranges

### Application Categories

| Category | Speed Range | Steps/Second | Use Cases |
| --- | --- | --- | --- |
| **Ultra Fast** | 1-10ms | 100-1000 | Emergency positioning, rapid testing |
| **Fast** | 10-100ms | 10-100 | Quick setup, repositioning |
| **Normal** | 100-2000ms | 0.5-10 | General operation, smooth movement |
| **Slow** | 2-30 seconds | 0.03-0.5 | Precise positioning, product photography |
| **Ultra Slow** | 30s-10 minutes | 0.002-0.03 | Timelapse, astronomy, artistic effects |
| **Extreme** | 10+ minutes | <0.002 | Long-term timelapse, scientific applications |

### Real-World Examples

**Product Photography Turntable**:

```javascript
// 360° rotation over 2 minutes with 72 positions (5° steps)
{
  steps: 72,
  delayMs: 1667,    // 1.667 seconds per step
  cycles: 1         // Single full rotation
}
```

**Sunset Timelapse**:

```javascript
// 2-hour sunset capture with 240 positions
{
  steps: 240,
  delayMs: 30000,   // 30 seconds per step
  cycles: 1         // Single sweep
}
```

**Macro Focus Stacking**:

```javascript
// 50 focus positions over 30 seconds
{
  steps: 50,
  delayMs: 600,     // 0.6 seconds per step
  cycles: 1         // Single focus sweep
}
```

**Astronomical Tracking**:

```javascript
// Earth rotation compensation (extremely slow)
{
  steps: 86400,     // Steps per day
  delayMs: 1000,    // 1 second per step
  cycles: 365       // Full year tracking
}
```

## Memory Optimization

### EEPROM Efficiency

- **Configuration**: 8 bytes (reduced from previous versions)
- **Loop Programs**: 16 bytes per program (compact format)
- **Complex Programs**: Variable length (step count dependent)
- **Total Storage**: Fits within Arduino Uno's 1024-byte EEPROM

### Performance Considerations

```cpp
// Long delay handling with responsiveness
void delayWithResponsiveness(uint32_t delayMs) {
  const uint32_t chunkSize = 100;  // 100ms chunks
  uint32_t remaining = delayMs;

  while (remaining > 0 && !programStopped) {
    uint32_t thisDelay = min(remaining, chunkSize);
    delay(thisDelay);
    remaining -= thisDelay;

    // Check for pause/stop commands during long delays
    checkForCommands();
  }
}
```

## WebUSB Interface

### Speed Input Control

```html
<div class="speed-control">
  <label for="manualSpeed">Speed (ms per step):</label>
  <input
    type="number"
    id="manualSpeed"
    value="1000"
    min="1"
    max="4294967295"
    title="1ms = very fast, 60000ms = 1 minute per step"
  />

  <div class="speed-presets">
    <button onclick="setSpeed(100)">Fast (100ms)</button>
    <button onclick="setSpeed(1000)">Normal (1s)</button>
    <button onclick="setSpeed(10000)">Slow (10s)</button>
    <button onclick="setSpeed(60000)">Very Slow (1min)</button>
  </div>
</div>
```

### Speed Validation

```javascript
validateSpeed(speed) {
  const minSpeed = 1;
  const maxSpeed = 4294967295;

  if (!speed || speed < minSpeed || speed > maxSpeed) {
    this.log(`Invalid speed: ${speed}. Must be between ${minSpeed} and ${maxSpeed} ms`, 'error');
    return false;
  }

  // Warn about very fast speeds
  if (speed < 50) {
    this.log(`Warning: Very fast speed (${speed}ms) - use caution`, 'warning');
  }

  // Info about very slow speeds
  if (speed > 60000) {
    const minutes = Math.round(speed / 60000);
    this.log(`Very slow speed: ${minutes} minute(s) per step`, 'info');
  }

  return true;
}
```

## Benefits

### Versatility

- **Full Range**: From emergency positioning to multi-day timelapse
- **Precision**: Millisecond-level timing control
- **Consistency**: Same units across all operations
- **Scalability**: Handles projects from seconds to months

### Performance

- **Memory Efficient**: Optimized binary protocols
- **Responsive**: Long delays broken into chunks for user interaction
- **Reliable**: Timeout and error handling for extreme durations
- **Cross-Platform**: Little-endian format ensures compatibility

### User Experience

- **Intuitive**: Speed in familiar time units (milliseconds)
- **Flexible**: Easy switching between different speed ranges
- **Persistent**: Speed preferences saved and restored
- **Safe**: Validation prevents harmful speed settings

This comprehensive speed system makes Motorillo suitable for virtually any motion control application, from rapid prototyping to professional cinematography and scientific research.

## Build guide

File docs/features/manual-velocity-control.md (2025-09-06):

# Manual Movement Velocity Control

This document describes the implementation of custom velocity control for manual movements in the Motorillo WebUSB interface.

## Overview

The Motorillo system provides flexible velocity control for manual movements through the web interface. Users can set custom movement speeds ranging from ultra-fast to extremely slow motion, perfect for various applications from quick positioning to precise timelapse work.

## WebUI Interface

### Velocity Control Element

```html
<div class="velocity-control">
  <label for="manualSpeed">Movement Speed (milliseconds per step):</label>
  <input type="number" id="manualSpeed" value="1000" min="1" max="4294967295" />
  <span class="help">
    Lower = faster, Higher = slower (1ms = very fast, 10000ms = very slow)
  </span>
</div>
```

### Features

- **Default Value**: 1000ms per step (balanced speed)
- **Range**: 1ms to 4,294,967,295ms (full 32-bit range)
- **Persistence**: Speed setting saved to localStorage and restored on page reload
- **Validation**: Input validation prevents invalid values with user feedback

## Command Protocol

### Unified Position Command

- **CMD_POS_WITH_SPEED (15)**: Move to any position with custom speed
  - Format: `position(2 bytes) + speed(4 bytes)`
  - Handles both regular moves and home operations (position 0)
  - Uses little-endian byte order for multi-byte values

### Simplified Protocol Benefits

- All manual movements use the unified position command with custom speed
- Home operation implemented as moving to position 0 with user-specified speed
- Simplified protocol while maintaining full functionality
- Consistent speed units (milliseconds) across all operations

## JavaScript Implementation

### Enhanced Movement Functions

```javascript
handleMove() {
  const position = parseInt(document.getElementById("targetPosition").value);
  const speed = parseInt(document.getElementById("manualSpeed").value);

  // Create binary command buffer
  const buffer = new ArrayBuffer(6);
  const view = new DataView(buffer);
  view.setUint16(0, position, true);  // Position (little-endian)
  view.setUint32(2, speed, true);     // Speed (little-endian)

  this.sendCommand(this.CMD_POS_WITH_SPEED, new Uint8Array(buffer));
}

handleHome() {
  const speed = parseInt(document.getElementById("manualSpeed").value);
  const position = 0; // Home is position 0

  // Uses same position command with position 0
  const buffer = new ArrayBuffer(6);
  const view = new DataView(buffer);
  view.setUint16(0, position, true);
  view.setUint32(2, speed, true);

  this.sendCommand(this.CMD_POS_WITH_SPEED, new Uint8Array(buffer));
}
```

### Input Validation & Persistence

- **Validation**: Checks for valid numeric input within acceptable range
- **Feedback**: Provides user feedback for invalid inputs with console logging
- **Storage**: `saveManualSpeed()` saves to localStorage on change
- **Restoration**: `loadManualSpeed()` restores saved speed on page load

## Arduino Firmware

### Unified Command Handler

```cpp
case CMD_POS_WITH_SPEED: {
  uint16_t position = *(uint16_t *)data;
  uint32_t speedMs = *(uint32_t *)(data + 2);
  moveToPositionWithSpeed(position, speedMs);
  // Handles both regular moves and home (when position = 0)
  break;
}
```

### Data Processing

- Processes little-endian byte order for cross-platform compatibility
- Position: 16-bit unsigned integer (0-65535 steps)
- Speed: 32-bit unsigned integer (1-4294967295 milliseconds per step)

## Usage Examples

### Application-Specific Speeds

| Use Case | Speed Range | Example  | Description |
| --- | --- | --- | --- |
| **Quick Testing** | 10-100ms | 50ms | Rapid positioning for setup |
| **Normal Operation** | 500-2000ms | 1000ms | Smooth, visible movement |
| **Precise Control**  | 2000-10000ms  | 5000ms | Careful positioning |
| **Timelapse Setup**  | 10000-60000ms | 30000ms  | Ultra-precise movement |
| **Long Exposure** | 60000ms+ | 300000ms | Extremely slow motion |

### Practical Examples

```javascript
// Fast positioning for quick adjustments
speed: 100ms  // 10 steps per second

// Standard operation for general use
speed: 1000ms // 1 step per second (default)

// Slow precision for critical positioning
speed: 5000ms // 1 step per 5 seconds

// Timelapse preparation
speed: 30000ms // 1 step per 30 seconds

// Ultra-slow for long exposure work
speed: 600000ms // 1 step per 10 minutes
```

## Benefits

1. **Flexibility**: Adaptable speed for different applications and requirements
2. **Precision**: Fine-grained control over movement timing
3. **Persistence**: User preferences remembered between sessions
4. **Safety**: Input validation prevents mechanical damage from excessive speeds
5. **Consistency**: Same millisecond units used throughout the system
6. **Simplicity**: Unified command protocol reduces complexity

## Speed Guidelines

### Safety Recommendations

- **1-50ms**: Use with caution - very fast movement may cause mechanical stress
- **50-500ms**: Fast but safe for most applications
- **500-2000ms**: Optimal range for general use
- **2000-30000ms**: Precision range for careful work
- **30000ms+**: Specialized applications (timelapse, astronomy)

### Application Guidelines

- **Product Photography**: 1000-5000ms for smooth rotation
- **Timelapse Setup**: 5000-30000ms for precise framing
- **Video Production**: 500-2000ms for smooth camera movements
- **Scientific Applications**: 10000ms+ for precise positioning
- **Art/Long Exposure**: 60000ms+ for creative effects

This flexible velocity control system makes Motorillo suitable for a wide range of applications, from rapid prototyping to professional cinematography and scientific research.

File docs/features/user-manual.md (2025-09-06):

# Motorillo User Manual

Welcome to Motorillo, your precision stepper motor controller for camera sliders, timelapses, and automation projects. This manual will guide you through all features and operations.

## Getting Started

### First Connection

1. **Power Up**: Connect your Arduino to computer via USB
2. **Open Browser**: Use Chrome or Edge (WebUSB required)
3. **Navigate**: Go to `http://localhost:8000` (after starting local server)
4. **Connect**: Click "Connect Slider" and select your Arduino device

### Initial Setup

**Configure Your Slider**:

- **Total Steps**: Set the maximum travel distance (default: 2000 steps)
- **Default Speed**: Set movement timing (default: 1000ms per step)
- **Acceleration**: Smoothness of speed changes (default: 50)

## Operating Modes

### WebUSB Mode (Browser Control)

When connected to browser, Motorillo provides full programming capabilities:

**Manual Controls**:

- **Position Movement**: Move to specific step positions
- **Speed Control**: Adjust movement speed from 1ms to hours per step
- **Home Functions**: Set reference points or return to home position

**Program Creation**:

- **Loop Programs**: Simple back-and-forth motion with timing control
- **Complex Programs**: Multi-waypoint sequences with variable speeds

### Standalone Mode (OLED + Button)

When WebUSB is disconnected, use physical controls:

**Navigation**:

- **Single Press**: Navigate through saved programs
- **Long Press**: Start/stop selected program
- **During Execution**: Single press pauses/resumes

**Display Information**:

- Current position and program status
- Selected program name and progress
- System mode and connection state

## Creating Motion Programs

### Loop Programs

Perfect for timelapse and repetitive motions:

```javascript
Program Settings:
- Name: "SUNSET" (up to 8 characters)
- Steps: 1000 (distance to travel)
- Delay: 30000ms (30 seconds between steps)
- Cycles: 1 (forward and back once)
```

**Use Cases**:

- **Timelapse**: Slow camera movement over time
- **Product Photography**: Rotating turntable sequences
- **Focus Stacking**: Macro photography depth sequences

### Complex Programs

For advanced multi-point sequences:

```javascript
Waypoint Example:
1. Position 0, Speed 2000ms, Pause 1000ms (slow start)
2. Position 500, Speed 1000ms, Pause 500ms (normal speed)
3. Position 1500, Speed 5000ms, Pause 2000ms (slow finish)
4. Position 0, Speed 1500ms, Pause 0ms (return home)
```

**Use Cases**:

- **Cinematography**: Complex camera movements
- **Automation**: Multi-step manufacturing sequences
- **Art Projects**: Custom motion patterns

## Speed Control Guide

### Understanding Speed Values

Speed is measured in **milliseconds per step**:

- **Lower values = Faster movement**
- **Higher values = Slower movement**

### Recommended Speed Ranges

| Application | Speed Range  | Example  | Duration Per Step |
| --- | --- | --- | --- |
| **Quick Setup** | 10-100ms | 50ms | 0.05 seconds |
| **Normal Operation**  | 500-2000ms | 1000ms | 1 second |
| **Smooth Timelapse**  | 5000-30000ms | 15000ms  | 15 seconds |
| **Ultra-Slow Motion** | 60000ms+ | 300000ms | 5 minutes |

### Speed Selection Tips

**For Different Projects**:

- **Product Photography**: 1000-5000ms (smooth rotation)
- **Sunset Timelapse**: 30000-120000ms (very slow movement)
- **Macro Focus Stack**: 500-2000ms (precise positioning)
- **Video Production**: 1000-3000ms (cinematic movement)

## Advanced Features

### Home Positioning

**Two Types of Home Operations**:

1. **Set Home (Green Button)**:

   - Sets current position as reference point
   - No motor movement
   - Use after manual positioning

2. **Go to Home (Orange Button)**:
   - Moves motor to position 0
   - Uses current speed setting
   - Use for returning to known position

### Program Management

**Saving Programs**:

- Up to 5 programs stored in Arduino memory
- Programs persist through power cycles
- WebUSB automatically loads saved programs

**Program Types**:

- **Loop Programs**: Simple back-and-forth (16 bytes each)
- **Complex Programs**: Multi-waypoint (variable size)

### Connection Management

**Automatic Mode Switching**:

- Arduino detects WebUSB connection automatically
- Switches between browser and standalone modes
- Graceful fallback if connection is lost

**Disconnection Handling**:

- Arduino continues operating with OLED interface
- All programs remain accessible via button navigation
- Reconnection restores full WebUSB functionality

## Practical Applications

### Timelapse Photography

**Basic Setup**:

1. Position camera at starting point
2. Use "Set Home (Current Position)"
3. Create loop program with desired duration
4. Start program and let it run

**Example - 2 Hour Sunset**:

```
Program: SUNSET
Steps: 240 (240 positions over travel)
Delay: 30000ms (30 seconds per step)
Cycles: 1 (single sweep)
Total Time: 240 × 30s = 2 hours
```

### Product Photography

**360° Turntable**:

```
Program: PRODUCT
Steps: 72 (72 positions = 5° per step)
Delay: 2000ms (2 seconds per position)
Cycles: 1 (full rotation)
Total Time: 72 × 2s = 2.4 minutes
```

### Video Production

**Smooth Camera Movement**:

```
Complex Program: CINEMATIC
- Start: Position 0, Speed 3000ms (slow start)
- Middle: Position 1000, Speed 1000ms (normal)
- End: Position 2000, Speed 5000ms (slow stop)
- Return: Position 0, Speed 2000ms (medium return)
```

### Focus Stacking

**Macro Photography**:

```
Program: FOCUS
Steps: 50 (50 focus positions)
Delay: 1000ms (1 second between shots)
Cycles: 1 (single pass)
Total Time: 50 seconds
```

## Troubleshooting Common Issues

### Connection Problems

**WebUSB Won't Connect**:

- Ensure Chrome/Edge browser (not Firefox/Safari)
- Check USB cable supports data (not power-only)
- Try different USB port on computer
- Restart browser and Arduino

**Connection Drops Frequently**:

- Check USB cable quality
- Verify stable power supply
- Move away from electromagnetic interference
- Try powered USB hub

### Movement Issues

**Motor Not Moving**:

- Verify wiring connections (STEP/DIR pins)
- Check motor driver power supply (12V)
- Test with slower speed settings
- Ensure motor driver is not overheating

**Wrong Direction**:

- Swap motor wires (A+ ↔ A- OR B+ ↔ B-)
- Or invert direction in firmware

**Skipping Steps**:

- Reduce speed (increase milliseconds per step)
- Check mechanical binding
- Verify adequate power supply current
- Adjust motor driver current limiting

### Display Issues

**OLED Blank**:

- Check I2C wiring (SDA/SCL connections)
- Verify power supply to display
- Try different I2C address in firmware

**Button Not Responding**:

- Check button wiring to pin 2 and GND
- Test button continuity with multimeter
- Verify pullup configuration in firmware

## Maintenance and Care

### Regular Maintenance

- Keep stepper motor and rails clean
- Check all connections periodically
- Update firmware when new versions available
- Backup important programs via WebUSB export

### Storage and Transport

- Power down system before moving
- Secure moving parts during transport
- Use "Set Home" to re-establish reference after setup

### Performance Optimization

- Use appropriate speeds for your mechanical system
- Consider microstepping for smoother motion
- Add proper heat sinking for motor drivers
- Use quality power supplies for stable operation

This user manual covers all essential operations. For technical details, troubleshooting, or development information, see the additional documentation in the `docs/` folder.

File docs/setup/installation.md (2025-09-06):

# Motorillo Installation Guide

This comprehensive guide covers everything needed to set up Motorillo, from hardware assembly to software configuration.

## Hardware Requirements

### Essential Components

| Component | Specification | Notes |
| --- | --- | --- |
| **Arduino Board**  | Leonardo, Micro, or Zero | WebUSB compatibility required |
| **Stepper Motor**  | NEMA 17 or similar | 200 steps/revolution recommended |
| **Motor Driver** | A4988, DRV8825, TMC2208  | Compatible with STEP/DIR interface |
| **Display** | SSD1306 OLED 96×16px | I2C interface (0.96" typical) |
| **Control Button** | Momentary push button | Normally open, any current rating  |
| **Power Supply** | 12V 2A minimum | Depends on motor specifications |
| **USB Cable** | USB-A to Micro-USB | For Arduino Leonardo/Micro |

### Optional Components

- **Enclosure**: Protect electronics and provide mounting points
- **Heat Sinks**: For motor driver thermal management
- **Limit Switches**: End-stop detection for safety
- **LED Indicators**: Status and power indication

## Wiring Diagram

### Arduino Leonardo/Micro Connections

```
┌─────────────────┐
│  Arduino Micro  │
├─────────────────┤
│ Pin 10 ────────────→ Motor Driver DIR
│ Pin 16 ────────────→ Motor Driver STEP
│ Pin 2  ────────────→ Control Button (other leg to GND)
│ VCC    ────────────→ OLED VCC (3.3V or 5V)
│ GND    ────────────→ OLED GND + Button + Motor Driver GND
│ SDA    ────────────→ OLED SDA (Pin A4 on Leonardo)
│ SCL    ────────────→ OLED SCL (Pin A5 on Leonardo)
│ USB    ────────────→ Computer (WebUSB + Power)
└─────────────────┘
```

### Motor Driver Connections (A4988/DRV8825)

```
┌─────────────────┐     ┌──────────────┐
│  Motor Driver   │     │ Stepper Motor│
├─────────────────┤     ├──────────────┤
│ DIR   ←──────── Pin 10│              │
│ STEP  ←──────── Pin 16│              │
│ ENABLE ←─────── GND   │              │
│ MS1   ←─────── GND    │ A+  ←────────┤ 1A
│ MS2   ←─────── GND    │ A-  ←────────┤ 1B
│ MS3   ←─────── GND    │ B+  ←────────┤ 2A
│ GND   ←─────── GND    │ B-  ←────────┤ 2B
│ VDD   ←─────── 5V     │              │
│ VMOT  ←─────── 12V    └──────────────┘
└─────────────────┘
```

## Software Installation

### Arduino IDE Setup

1. **Install Arduino IDE**:

   ```bash
   # Download from https://www.arduino.cc/en/software
   # Or via package manager (macOS):
   brew install --cask arduino
   ```

2. **Install Required Libraries**:

   - Open Arduino IDE → Tools → Manage Libraries
   - Search and install:
     - `Adafruit SSD1306` (display support)
     - `Adafruit GFX Library` (graphics)
     - `WebUSB` (USB communication)

3. **Board Configuration**:
   ```
   Board: Arduino Leonardo (or Micro/Zero)
   Port: /dev/cu.usbmodem* (varies by system)
   Programmer: AVRISP mkII
   ```

### Library Dependencies

**Required Libraries** (install via Library Manager):

```cpp
#include <Adafruit_GFX.h>      // Graphics library
#include <Adafruit_SSD1306.h>  // OLED display support
#include <EEPROM.h>            // Configuration storage
#include <WebUSB.h>            // WebUSB communication
#include <Wire.h>              // I2C communication
```

**Auto-installed Dependencies**:

- Adafruit BusIO
- Adafruit GFX Library dependencies

## Firmware Installation

### Download and Upload

1. **Clone Repository**:

   ```bash
   git clone https://github.com/yourusername/motorillo.git
   cd motorillo
   ```

2. **Open Firmware**:

   - Open `motorillo.ino` in Arduino IDE
   - Verify all includes are resolved (no red underlines)

3. **Compile and Upload**:

   ```
   Arduino IDE → Sketch → Upload
   Or press Ctrl+U (Cmd+U on macOS)
   ```

4. **Verify Installation**:
   - OLED should display "Motorillo v1.0"
   - Serial monitor shows WebUSB initialization
   - Button press cycles through menu items

### Configuration Verification

**Check Pin Assignments** (in `src/motor_control.h`):

```cpp
#define STEP_PIN 16    // Verify matches your wiring
#define DIR_PIN 10     // Verify matches your wiring
#define BUTTON_PIN 2   // Button with internal pullup
```

**Check Display Settings** (in `src/display_manager.h`):

```cpp
#define SCREEN_WIDTH 128   // OLED width in pixels
#define SCREEN_HEIGHT 32   // OLED height in pixels (16 for smaller displays)
#define OLED_RESET -1      // Reset pin (-1 if not used)
```

## WebUSB Interface Setup

### Browser Requirements

**Compatible Browsers**:

- Google Chrome 61+
- Microsoft Edge 79+
- Opera 48+
- **Not supported**: Firefox, Safari

### Local Server Setup

1. **Navigate to WebUSB Directory**:

   ```bash
   cd motorillo/webusb
   ```

2. **Start Local Server** (choose one method):

   **Option A - Python 3**:

   ```bash
   python -m http.server 8000
   ```

   **Option B - Python 2**:

   ```bash
   python -m SimpleHTTPServer 8000
   ```

   **Option C - Node.js**:

   ```bash
   npx http-server -p 8000
   ```

   **Option D - PHP**:

   ```bash
   php -S localhost:8000
   ```

3. **Access Interface**:
   - Open Chrome/Edge browser
   - Navigate to `http://localhost:8000`
   - Click "Connect Slider" button
   - Select Arduino device from popup

### WebUSB Permissions

**Grant USB Access**:

1. Browser will show device selection popup
2. Select your Arduino board (should show as "Arduino Leonardo" or similar)
3. Click "Connect" to establish WebUSB connection
4. Interface should show "Connected" status

**Troubleshooting Permissions**:

- Ensure Arduino is plugged in and powered
- Try different USB ports/cables
- Check browser console for error messages
- Verify WebUSB library is properly included in firmware

## Initial Configuration

### Basic Settings

1. **Connect via WebUSB Interface**:

   - Browser shows connection status
   - Arduino display switches to "Programming Mode"

2. **Set Basic Parameters**:

   ```javascript
   // Default configuration
   Total Steps: 2000        // Adjust for your slider length
   Default Speed: 1000ms    // 1 second per step
   Acceleration: 50         // Smooth acceleration
   Microstepping: 1         // Full steps (adjust for driver)
   ```

3. **Test Movement**:
   - Use manual controls to verify direction
   - Check speed feels appropriate
   - Ensure position tracking is accurate

### Motor Calibration

**Direction Setup**:

1. Test movement in both directions
2. If backward, swap motor wires A+ ↔ A- or B+ ↔ B-
3. Alternatively, invert `DIR_PIN` logic in firmware

**Speed Calibration**:

1. Start with 1000ms per step (safe default)
2. Adjust based on mechanical constraints
3. Test various speeds: 100ms (fast) to 10000ms (slow)

**Position Calibration**:

1. Manually position slider at one end
2. Use "Set Home (Current Position)"
3. Test movement to other end
4. Adjust "Total Steps" configuration as needed

## Verification Checklist

### Hardware Tests

- [ ] OLED display shows startup message
- [ ] Button press changes display menu
- [ ] Motor responds to movement commands
- [ ] Direction is correct for intended application
- [ ] No unusual heating of driver or motor
- [ ] All connections are secure

### Software Tests

- [ ] Arduino IDE compiles without errors
- [ ] Firmware uploads successfully
- [ ] Serial monitor shows initialization messages
- [ ] WebUSB interface loads in browser
- [ ] Connection establishes successfully
- [ ] Manual controls work in both directions

### Integration Tests

- [ ] Create and run simple loop program
- [ ] Test program saving/loading
- [ ] Verify speed control works
- [ ] Check position tracking accuracy
- [ ] Test disconnection/reconnection

## Troubleshooting

### Hardware Issues

**OLED Display Not Working**:

- Check I2C connections (SDA/SCL)
- Verify power supply (3.3V or 5V)
- Try different I2C address (0x3C or 0x3D)
- Use I2C scanner sketch to detect device

**Motor Not Moving**:

- Check STEP/DIR pin connections
- Verify motor driver power supply
- Test with different speed settings
- Check motor wiring order
- Ensure ENABLE pin is pulled low

**Button Not Responding**:

- Verify button wiring (one leg to pin 2, other to GND)
- Check for proper debouncing in firmware
- Test with multimeter for continuity

### Software Issues

**Compilation Errors**:

- Install all required libraries
- Check Arduino board selection
- Verify USB cable supports data (not power-only)
- Try different USB port

**WebUSB Connection Failed**:

- Use Chrome/Edge browser only
- Ensure HTTPS or localhost origin
- Check Arduino is running WebUSB firmware
- Verify USB cable supports data communication

**Position Drift**:

- Check for missed steps (speed too fast)
- Verify power supply stability
- Ensure proper microstepping configuration
- Check for mechanical binding

### Performance Issues

**Slow Response**:

- Reduce delay values in firmware
- Optimize WebUSB communication
- Check for memory constraints
- Profile critical code sections

**Memory Errors**:

- Remove debug Serial.print() statements
- Optimize string usage
- Reduce program storage if needed
- Consider using F() macro for constants

This installation guide should get Motorillo up and running reliably. For additional help, check the troubleshooting section or consult the development documentation.

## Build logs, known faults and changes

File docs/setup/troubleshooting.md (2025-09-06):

# Motorillo Troubleshooting Guide

This guide covers common issues and solutions for Motorillo setup and operation.

## Connection Issues

### WebUSB Connection Problems

**Problem**: Browser shows "No compatible devices found"

**Solutions**:

1. **Check Browser Compatibility**:

   - Use Chrome 61+ or Edge 79+ (Firefox/Safari not supported)
   - Ensure JavaScript is enabled
   - Try incognito/private mode to rule out extensions

2. **Verify Arduino Setup**:

   ```bash
   # Check if Arduino is detected by system
   # macOS/Linux:
   ls /dev/cu.usbmodem*
   ls /dev/ttyACM*

   # Windows:
   # Check Device Manager for COM ports
   ```

3. **Firmware Verification**:
   - Confirm WebUSB library is included in firmware
   - Check Serial Monitor shows "WebUSB initialized"
   - Verify Arduino board supports WebUSB (Leonardo/Micro/Zero)

**Problem**: Connection drops frequently

**Solutions**:

1. **Cable Issues**:

   - Try different USB cable (ensure data support, not power-only)
   - Test different USB ports on computer
   - Check for loose connections

2. **Power Supply**:

   - Ensure stable power supply to Arduino
   - Check if motor driver draws too much current
   - Try powered USB hub if computer USB is weak

3. **Interference**:
   - Move away from electromagnetic interference sources
   - Check for ground loops in wiring
   - Ensure proper shielding on stepper motor cables

### Serial Communication Issues

**Problem**: Commands not reaching Arduino

**Solutions**:

1. **Check Serial Settings**:

   ```cpp
   // Verify in firmware
   Serial.begin(9600);  // Baud rate must match
   ```

2. **Buffer Issues**:

   - Add delays between rapid commands
   - Check for buffer overflow in Serial communication
   - Monitor Serial.available() in firmware

3. **Binary Protocol**:
   ```javascript
   // Ensure proper binary encoding
   const view = new DataView(buffer);
   view.setUint16(0, position, true); // Little-endian required
   view.setUint32(2, speed, true);
   ```

## Hardware Issues

### Motor Problems

**Problem**: Motor not moving

**Diagnostic Steps**:

1. **Check Connections**:

   ```
   Arduino Pin 10 → Driver DIR
   Arduino Pin 16 → Driver STEP
   Arduino GND    → Driver GND
   ```

2. **Motor Driver Power**:

   - Verify 12V power to VMOT pin
   - Check 5V logic power to VDD pin
   - Ensure GND connections are solid

3. **Test Movement**:
   ```cpp
   // Simple test sketch
   digitalWrite(STEP_PIN, HIGH);
   delayMicroseconds(1000);
   digitalWrite(STEP_PIN, LOW);
   delayMicroseconds(1000);
   ```

**Problem**: Motor moves wrong direction

**Solutions**:

1. **Swap Motor Wires**:

   - Swap A+ ↔ A- OR B+ ↔ B- (not both)
   - This reverses rotation direction

2. **Software Inversion**:
   ```cpp
   // In motor_control.cpp
   digitalWrite(DIR_PIN, !targetDirection);  // Invert direction
   ```

**Problem**: Motor skips steps or vibrates

**Solutions**:

1. **Speed Adjustment**:

   - Increase delay between steps (slower speed)
   - Check mechanical load isn't too high
   - Verify acceleration settings

2. **Driver Configuration**:

   - Check microstepping pins (MS1, MS2, MS3)
   - Adjust current limiting potentiometer
   - Ensure driver heat sink is adequate

3. **Power Supply**:
   - Verify adequate current capacity (2A minimum)
   - Check voltage stability under load
   - Add capacitors if voltage drops during stepping

### Display Issues

**Problem**: OLED display blank or corrupted

**Solutions**:

1. **I2C Connection Check**:

   ```cpp
   // Test I2C scanner
   #include <Wire.h>

   void setup() {
     Wire.begin();
     Serial.begin(9600);

     for(byte addr = 1; addr < 127; addr++) {
       Wire.beginTransmission(addr);
       if(Wire.endTransmission() == 0) {
         Serial.print("Device found at 0x");
         Serial.println(addr, HEX);
       }
     }
   }
   ```

2. **Display Initialization**:

   - Try different I2C addresses (0x3C, 0x3D)
   - Check power supply voltage (3.3V or 5V)
   - Verify display resolution settings

3. **Wiring Verification**:
   ```
   Arduino SDA (A4) → OLED SDA
   Arduino SCL (A5) → OLED SCL
   Arduino VCC      → OLED VCC
   Arduino GND      → OLED GND
   ```

**Problem**: Button not responding

**Solutions**:

1. **Check Wiring**:

   ```
   Button Pin 1 → Arduino Pin 2
   Button Pin 2 → Arduino GND
   ```

2. **Test Button**:

   ```cpp
   // Simple button test
   pinMode(2, INPUT_PULLUP);
   Serial.println(digitalRead(2));  // Should toggle with button press
   ```

3. **Debouncing**:
   - Ensure proper debouncing in firmware
   - Add small capacitor across button if needed
   - Check for proper pullup configuration

## Software Issues

### Compilation Problems

**Problem**: Library not found errors

**Solutions**:

1. **Install Missing Libraries**:

   ```
   Arduino IDE → Tools → Manage Libraries
   Search and install:
   - Adafruit SSD1306
   - Adafruit GFX Library
   - WebUSB
   ```

2. **Library Path Issues**:
   - Restart Arduino IDE after library installation
   - Check Documents/Arduino/libraries folder
   - Manually install libraries if needed

**Problem**: "Board not supported" errors

**Solutions**:

1. **Board Selection**:

   ```
   Tools → Board → Arduino Leonardo (or Micro/Zero)
   ```

2. **Core Installation**:
   - Ensure Arduino AVR Boards core is installed
   - Update board definitions if needed

### Runtime Errors

**Problem**: Memory errors or crashes

**Solutions**:

1. **Memory Optimization**:

   ```cpp
   // Use F() macro for string constants
   Serial.println(F("Message"));

   // Remove debug messages in production
   #ifdef DEBUG
     Serial.print("Debug info");
   #endif
   ```

2. **EEPROM Issues**:
   ```cpp
   // Check EEPROM bounds
   if(address < EEPROM.length()) {
     EEPROM.write(address, data);
   }
   ```

**Problem**: Position tracking drift

**Solutions**:

1. **Check for Missed Steps**:

   - Reduce maximum speed
   - Increase acceleration time
   - Verify mechanical load

2. **Encoder Feedback** (if available):
   ```cpp
   // Add position verification
   if(abs(encoderPosition - calculatedPosition) > threshold) {
     // Recalibrate position
     currentPosition = encoderPosition;
   }
   ```

## Performance Issues

### Slow Response

**Problem**: Laggy web interface or motor response

**Solutions**:

1. **Optimize Communication**:

   - Reduce polling frequency
   - Use binary commands instead of text
   - Batch multiple commands

2. **Firmware Optimization**:

   ```cpp
   // Reduce delay in main loop
   delay(10);  // Instead of delay(100)

   // Use non-blocking delays for long operations
   if(millis() - lastUpdate > updateInterval) {
     updateDisplay();
     lastUpdate = millis();
   }
   ```

### Memory Constraints

**Problem**: Running out of RAM or program space

**Solutions**:

1. **String Optimization**:

   ```cpp
   // Store strings in flash memory
   const char message[] PROGMEM = "Long message text";

   // Use character arrays instead of String objects
   char buffer[20];
   strcpy(buffer, "message");
   ```

2. **Code Optimization**:
   - Remove unused functions and variables
   - Combine similar functions
   - Use more efficient data types

## Debugging Tools

### Serial Monitor Debugging

```cpp
// Enable verbose debugging
#define DEBUG 1

#ifdef DEBUG
  #define DEBUG_PRINT(x) Serial.print(x)
  #define DEBUG_PRINTLN(x) Serial.println(x)
#else
  #define DEBUG_PRINT(x)
  #define DEBUG_PRINTLN(x)
#endif

// Usage
DEBUG_PRINTLN("Motor moving to position: " + String(targetPos));
```

### WebUSB Console Logging

```javascript
// Enhanced logging with timestamps
log(message, level = 'info') {
  const timestamp = new Date().toLocaleTimeString();
  const logMessage = `[${timestamp}] ${message}`;

  console.log(logMessage);

  // Optional: Display in UI log area
  const logArea = document.getElementById('logArea');
  if (logArea) {
    logArea.innerHTML += `<div class="${level}">${logMessage}</div>`;
    logArea.scrollTop = logArea.scrollHeight;
  }
}
```

### Hardware Testing

**Multimeter Checks**:

- Voltage at motor driver pins (5V, 12V, GND)
- Continuity of all connections
- Signal integrity at STEP/DIR pins

**Oscilloscope (if available)**:

- STEP pulse timing and amplitude
- DIR signal timing relative to STEP
- I2C communication signals (SDA/SCL)

## Getting Help

### Information to Gather

Before seeking help, collect:

1. **Hardware Setup**:

   - Arduino board model
   - Motor driver type
   - Stepper motor specifications
   - Power supply voltage/current

2. **Software Versions**:

   - Arduino IDE version
   - Library versions (check Library Manager)
   - Firmware compilation date

3. **Error Details**:

   - Exact error messages
   - When problem occurs (startup, during operation, etc.)
   - Steps to reproduce issue

4. **Serial Output**:
   ```bash
   # Capture serial monitor output
   # Include startup messages and error conditions
   ```

### Support Resources

- **GitHub Issues**: Report bugs with detailed reproduction steps
- **Arduino Forum**: Community help for hardware/software issues
- **Documentation**: Check other sections of this guide
- **Example Code**: Reference working examples in repository

This troubleshooting guide should resolve most common issues. For persistent problems, provide detailed information when seeking help to enable faster resolution.

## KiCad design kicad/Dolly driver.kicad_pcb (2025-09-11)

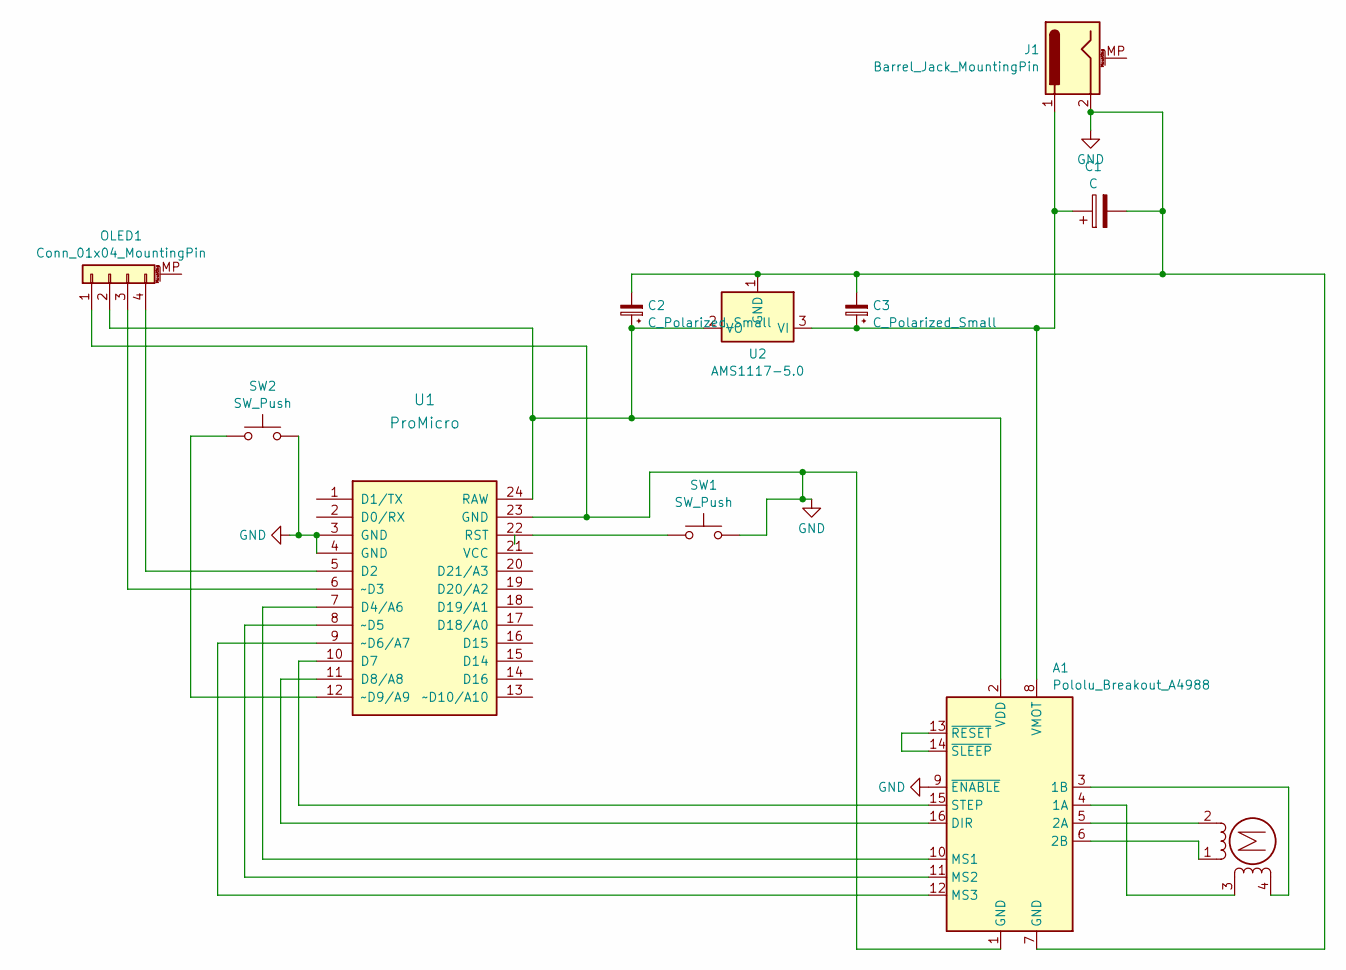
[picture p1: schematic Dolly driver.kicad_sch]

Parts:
A1: Pololu_Breakout_A4988; Pololu_Breakout-16_15.2x20.3mm
C1: C; CP_Radial_D6.3mm_P2.50mm
C2, C3: C_Polarized_Small; CP_Radial_D5.0mm_P2.50mm
J1: Barrel_Jack_MountingPin; BarrelJack_GCT_DCJ200-10-A_Horizontal
M1: Stepper_Motor_bipolar; PinHeader_1x04_P2.54mm_Vertical
OLED1: Conn_01x04_MountingPin; PinHeader_1x04_P2.54mm_Vertical
SW1, SW2: SW_Push; SW_Tactile_SPST_NO_Straight_CK_PTS636Sx25SMTRLFS
U1: ProMicro; ArduinoProMicro
U2: AMS1117-5.0; SOT-223-3_TabPin2

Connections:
GND: A1.1 (GND), A1.7 (GND), A1.9 (~ENABLE), C1.2, C2.2, C3.2, J1.2, OLED1.1 (GND), SW1.2, SW2.2, U1.3 (GND), U1.4 (GND), U1.23 (GND), U2.1 (GND)
unnamed: A1.4 (1A), M1.3
unnamed: A1.3 (1B), M1.4
unnamed: A1.5 (2A), M1.2 (-)
unnamed: A1.6 (2B), M1.1
unnamed: A1.16 (DIR), U1.11 (D8/A8)
unnamed: A1.10 (MS1), U1.7 (D4/A6)
unnamed: A1.11 (MS2), U1.8 (~D5)
unnamed: A1.12 (MS3), U1.9 (~D6/A7)
unnamed: A1.15 (STEP), U1.10 (D7)
unnamed: A1.2 (VDD), C2.1, OLED1.2 (VCC), U1.24 (RAW), U2.2 (VO)
unnamed: A1.8 (VMOT), C1.1, C3.1, J1.1, U2.3 (VI)
unnamed: A1.13 (~RESET), A1.14 (~SLEEP)
unnamed: OLED1.3 (SCL), U1.6 (~D3)
unnamed: OLED1.4 (SDA), U1.5 (D2)
unnamed: SW1.1, U1.22 (RST)
unnamed: SW2.1, U1.12 (~D9/A9)

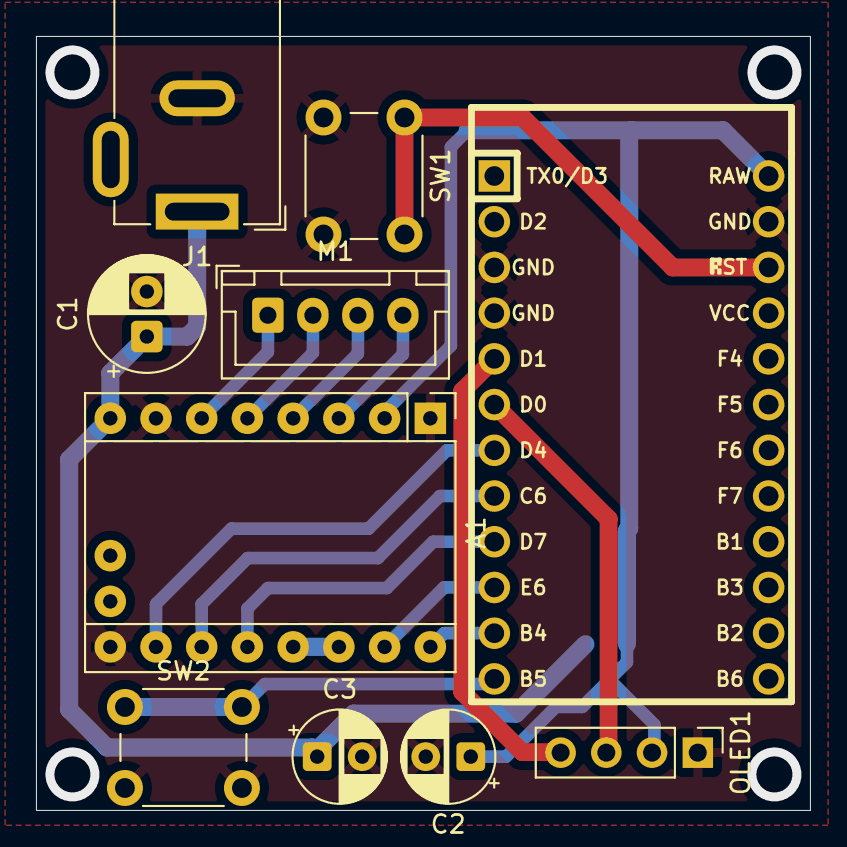
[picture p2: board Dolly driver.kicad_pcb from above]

Board: 2 copper layers, 43.0 x 43.0 mm, 11 parts (1 on the bottom side), 17 nets.

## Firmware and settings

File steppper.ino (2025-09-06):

#include <Adafruit_GFX.h>
#include <Adafruit_SSD1306.h>
#include <EEPROM.h>
#include <WebUSB.h>
#include <Wire.h>

// Include our modular headers
#include "src/command_processor.h"
#include "src/config_manager.h"
#include "src/display_manager.h"
#include "src/menu_system.h"
#include "src/motor_control.h"

/**
 * Creating an instance of WebUSBSerial will add an additional USB interface to
 * the device that is marked as vendor-specific (rather than USB CDC-ACM) and
 * is therefore accessible to the browser.
 *
 * The URL here provides a hint to the browser about what page the user should
 * navigate to to interact with the device.
 */
WebUSB WebUSBSerial(1 /* https:// */, "localhost:8000");

#define Serial WebUSBSerial

// Global variables
long currentPosition = 0;
bool programmingMode = false;

// WebUSB connection detection
unsigned long bootTime = 0;
const unsigned long serialWaitTime =
    3000; // Wait 3 seconds for WebUSB connection
bool serialCheckComplete = false;

// WebUSB disconnection detection
unsigned long lastWebUSBActivity = 0;
const unsigned long webUSBTimeoutMs =
    3000; // Reduced to 3 seconds for faster detection
bool wasInProgrammingMode = false;

// Main program variables
bool programRunning = false;
bool programPaused = false;

// Function to send all EEPROM data immediately on connection
void sendAllEEPROMData() {
  // Count valid programs (only loop programs)
  uint8_t programCount = 0;
  for (uint8_t i = 0; i < MAX_PROGRAMS; i++) {
    uint8_t progType = getProgramType(i);
    if (progType == PROGRAM_TYPE_LOOP) {
      programCount++;
    }
  }

  // Send program count first
  Serial.print("PROGRAMS:");
  Serial.println(programCount);
  Serial.flush();
  delay(100); // Allow program count to be processed

  // Send each program as text
  for (uint8_t i = 0; i < MAX_PROGRAMS; i++) {
    uint8_t programType = getProgramType(i);
    if (programType != PROGRAM_TYPE_LOOP)
      continue;

    char name[9];
    loadProgramName(i, name);

    LoopProgram loopProg;
    if (loadLoopProgram(i, &loopProg)) {
      Serial.print("PROG:");
      Serial.print(i);
      Serial.print(",");
      Serial.print(name);
      Serial.print(",");
      Serial.print(loopProg.steps);
      Serial.print(",");
      Serial.println(loopProg.delayMs);
      Serial.flush();
      delay(50); // Allow each program to be processed
    }
  }
  Serial.flush();
}

void setup() {
  // Always start Serial for WebUSB
  Serial.begin(9600);
  bootTime = millis();
  programmingMode =
      false; // Start in standalone mode, will switch if WebUSB connects

  // Setup all modules
  setupMotorPins();
  setupButton();
  setupDisplay();

  // Set yield callback for motor control
  setYieldCallback(checkButton);

  loadConfig();

  // Build menu items based on stored programs
  buildMenuItems();

  // Update display with initial status
  updateDisplay();
}

void loop() {
  // Check for WebUSB connection during boot period
  if (!serialCheckComplete) {
    if (Serial && (millis() - bootTime < serialWaitTime)) {
      // WebUSB is available, switch to programming mode
      if (!programmingMode) {
        programmingMode = true;
      }
    } else if (millis() - bootTime >= serialWaitTime) {
      // Timeout reached, finalize mode
      serialCheckComplete = true;
      // If still in standalone mode, enter menu by default
      if (!programmingMode && !inMenuMode) {
        enterMenuMode();
      }
    }
  }

  // Continue to check for WebUSB connection even after boot
  if (serialCheckComplete && !programmingMode && Serial) {
    programmingMode = true;
    wasInProgrammingMode = true;
    lastWebUSBActivity = millis(); // Update activity timestamp
    // Exit menu mode when switching to programming mode
    if (inMenuMode) {
      exitMenuMode();
    }

    Serial.println("WebUSB Connected");
    delay(100); // Brief stabilization delay
    sendAllEEPROMData();
  }

  // Detect WebUSB disconnection
  if (programmingMode && serialCheckComplete) {
    // Check if we haven't received any data for a while
    if (millis() - lastWebUSBActivity > webUSBTimeoutMs) {
      // WebUSB seems to be disconnected
      programmingMode = false;
      wasInProgrammingMode = false;
      // Enter menu mode automatically
      if (!inMenuMode) {
        enterMenuMode();
      }
      updateDisplay(); // Update display to show new mode
    }
  }

  // Check button state (with debouncing)
  if (!programmingMode) {
    checkButton();
  }

  // Update display periodically
  if (millis() - lastDisplayUpdate > DISPLAY_UPDATE_INTERVAL) {
    updateDisplay();
    lastDisplayUpdate = millis();
  }

  if (programmingMode && Serial && Serial.available()) {
    // Update activity timestamp when we receive data
    lastWebUSBActivity = millis();

    // Check if this is a binary command (first byte < 20)
    uint8_t firstByte = Serial.peek();

    if (firstByte < 20) {
      // Binary command - read command code
      uint8_t cmdCode = Serial.read();

      // Read all available data as binary payload
      uint8_t data[64];
      int dataLen = 0;
      delay(1); // Small delay to ensure all data is available

      while (Serial.available() && dataLen < sizeof(data)) {
        data[dataLen++] = Serial.read();
      }

      // Process the binary command
      processCommandCode(cmdCode, (char *)data, dataLen);
    }
  } else if (!programmingMode && programRunning) {
    executeStoredProgram();
  } else {
    // Program stopped, just idle
    delay(50);
  }
}

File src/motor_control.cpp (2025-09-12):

#include "motor_control.h"
#include "config_manager.h"
#include "display_manager.h"
#include "menu_system.h"

// External variables (defined in main sketch)
extern long currentPosition;
extern bool programPaused;
extern bool programRunning;

// Function pointer for yield callback
typedef void (*YieldCallback)();

// Global yield callback - can be set by different modules
YieldCallback yieldCallback = nullptr;

// Set the yield callback function
void setYieldCallback(YieldCallback callback) { yieldCallback = callback; }

// Generic yielding delay function - calls whatever callback is registered
void yieldingDelay(uint32_t delayMs) {
  const uint32_t YIELD_CHUNK_MS = 10; // Check every 10ms for responsiveness

  if (delayMs <= YIELD_CHUNK_MS) {
    // Short delay - use regular delay but still yield
    delay(delayMs);
    if (yieldCallback)
      yieldCallback(); // Call registered yield function
    return;
  }

  uint32_t remaining = delayMs;
  while (remaining > 0 && !programPaused && programRunning) {
    uint32_t thisChunk = min(remaining, YIELD_CHUNK_MS);
    delay(thisChunk);
    remaining -= thisChunk;

    // Yield to registered callback
    if (yieldCallback)
      yieldCallback();

    // Early exit if paused or stopped
    if (programPaused || !programRunning) {
      break;
    }
  }
}

// Setup motor control pins
void setupMotorPins() {
  pinMode(STEP_PIN, OUTPUT);
  pinMode(DIR_PIN, OUTPUT);
  pinMode(MS1_PIN, OUTPUT);
  pinMode(MS2_PIN, OUTPUT);
  // pinMode(MS3_PIN, OUTPUT);
}

// Set microstepping mode using MS pins
void setMicrostepping(uint8_t mode) {
  // TODO: TMC2209 1/16 step
  digitalWrite(MS1_PIN, LOW);
  digitalWrite(MS2_PIN, LOW);
  // switch (mode)
  // {
  // case FULL_STEP: // Full step: L,L,L
  //   digitalWrite(MS1_PIN, LOW);
  //   digitalWrite(MS2_PIN, LOW);
  //   digitalWrite(MS3_PIN, LOW);
  //   break;
  // case HALF_STEP: // Half step: H,L,L
  //   digitalWrite(MS1_PIN, HIGH);
  //   digitalWrite(MS2_PIN, LOW);
  //   digitalWrite(MS3_PIN, LOW);
  //   break;
  // case QUARTER_STEP: // Quarter step: L,H,L
  //   digitalWrite(MS1_PIN, LOW);
  //   digitalWrite(MS2_PIN, HIGH);
  //   digitalWrite(MS3_PIN, LOW);
  //   break;
  // case EIGHTH_STEP: // Eighth step: H,H,L
  //   digitalWrite(MS1_PIN, HIGH);
  //   digitalWrite(MS2_PIN, HIGH);
  //   digitalWrite(MS3_PIN, LOW);
  //   break;
  // case SIXTEENTH_STEP: // Sixteenth step: H,H,H
  //   digitalWrite(MS1_PIN, HIGH);
  //   digitalWrite(MS2_PIN, HIGH);
  //   digitalWrite(MS3_PIN, HIGH);
  //   break;
  // default: // Default to full step for invalid values
  //   digitalWrite(MS1_PIN, LOW);
  //   digitalWrite(MS2_PIN, LOW);
  //   digitalWrite(MS3_PIN, LOW);
  //   break;
  // }
}

// Motor control functions

// Move to position with specified speed (in milliseconds)
void moveToPositionWithSpeed(long targetPosition, uint32_t speedMs) {
  long stepsToMove = abs(targetPosition - currentPosition);
  bool direction = targetPosition > currentPosition;

  // Adjust for microstepping - need more pulses but faster timing to maintain
  // same speed
  long actualStepsToMove = stepsToMove * DEFAULT_MICROSTEPPING;
  uint32_t adjustedSpeedMs = speedMs / DEFAULT_MICROSTEPPING;

  digitalWrite(DIR_PIN, direction ? HIGH : LOW);

  // Simplified acceleration (removed complex calculations to save space)
  for (long i = 0; i < actualStepsToMove; i++) {
    // Check for pause/stop request during movement
    if (programPaused || !programRunning) {
      currentPosition += direction ? (i / DEFAULT_MICROSTEPPING)
                                   : -(i / DEFAULT_MICROSTEPPING);
      return;
    }

    digitalWrite(STEP_PIN, HIGH);
    yieldingDelay(adjustedSpeedMs);
    digitalWrite(STEP_PIN, LOW);
    yieldingDelay(adjustedSpeedMs);

    // Update display less frequently to reduce overhead
    if (i % 10 == 0) {
      updateDisplay(i / DEFAULT_MICROSTEPPING);
    }
  }

  currentPosition = targetPosition;
}

// Run a loop program (infinite forward/backward motion)
void runLoopProgram(uint8_t programId) {
  LoopProgram loopProg;
  if (!loadLoopProgram(programId, &loopProg)) {
    Serial.println("ERROR: Failed to load loop program");
    return; // Failed to load loop program
  }

  // Run infinite cycles until stopped or paused
  while (programRunning && !programPaused) {
    // Forward movement
    long targetPosition = currentPosition + loopProg.steps;
    moveToPositionWithSpeed(targetPosition, loopProg.delayMs);

    // Check if we should stop/pause after forward movement
    if (!programRunning || programPaused) {
      break;
    }

    // Brief pause at end of forward movement with yielding
    yieldingDelay(100);

    // Backward movement
    targetPosition = currentPosition - loopProg.steps;
    moveToPositionWithSpeed(targetPosition, loopProg.delayMs);

    // Check if we should stop/pause after backward movement
    if (!programRunning || programPaused) {
      break;
    }

    // Brief pause at end of backward movement with yielding
    yieldingDelay(100);
  }

  if (programPaused) {
    Serial.println("Program paused");
  } else {
    Serial.println("Program stopped");
  }
}

// Execute stored program (called from main loop)
void executeStoredProgram() {
  // Don't execute if paused
  if (programPaused) {
    yieldingDelay(100); // Yielding delay while paused
    return;
  }

  if (config.programCount > 0) {
    // Run the selected program from menu, or first program if no menu selection
    int programToRun = 0;

    // If we came from menu selection, use the selected program
    if (menuItemCount > 0 && currentMenuIndex < menuItemCount) {
      MenuItem selectedItem = menuItems[currentMenuIndex];
      if (selectedItem.type == 0) { // It's a program
        programToRun = selectedItem.id;
      }
    }

    // Check program type and run appropriate function
    uint8_t programType = getProgramType(programToRun);
    if (programType == PROGRAM_TYPE_LOOP) {
      runLoopProgram(programToRun);
    } else {
      Serial.println(F("ERROR: Invalid program type"));
      return;
    }
  } else {
    // No program stored, just idle with yielding
    yieldingDelay(100);
  }
}

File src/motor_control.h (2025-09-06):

#ifndef MOTOR_CONTROL_H
#define MOTOR_CONTROL_H

#include "menu_system.h"
#include <Arduino.h>

// Pin definitions
const int MS1_PIN = 4;
const int MS2_PIN = 5;
const int MS3_PIN = 6;
const int STEP_PIN = 7;
const int DIR_PIN = 8;

// Microstepping modes
enum MicrostepMode {
  FULL_STEP = 1,
  HALF_STEP = 2,
  QUARTER_STEP = 4,
  EIGHTH_STEP = 8,
  SIXTEENTH_STEP = 16
};

// External variables from menu system
extern MenuItem menuItems[];
extern int menuItemCount;
extern int currentMenuIndex;

// Yield callback function pointer type
typedef void (*YieldCallback)();

// Function declarations
void setupMotorPins();
void setMicrostepping(uint8_t mode);
void setYieldCallback(YieldCallback callback); // Set yield callback
void yieldingDelay(
    uint32_t delayMs); // Non-blocking delay with callback yielding
void moveToPositionWithSpeed(long targetPosition, uint32_t speedMs);
void runProgram(uint8_t programId);
void runLoopProgram(uint8_t programId);
void executeStoredProgram();

#endif // MOTOR_CONTROL_H

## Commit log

2025-09-05 Add motor control functionality and UI enhancements
    - Implement motor control logic in motor_control.cpp and motor_control.h.
    - Refactor main sketch (steppper.ino) to utilize modular motor control functions.
    - Update web interface to support speed unit selection (microseconds/milliseconds) for default speed and step speeds.
    - Enhance UI with new buttons for setting home position and improved layout for speed inputs.
    - Style adjustments in CSS for better user experience with speed input groups and home control buttons.
2025-09-05 Refactor program storage and management in config_manager
    - Introduced new program types: loop and complex, with efficient storage.
    - Added functions to save and load loop programs, including parameters for steps, delay, cycles, and speed unit.
    - Updated existing complex program functions to align with new storage format.
    - Enhanced EEPROM structure to accommodate new program types and sizes.
    - Implemented legacy functions for backward compatibility with existing complex programs.
    - Simplified motor control logic for running loop programs and handling movement.
    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
2025-09-05 Refactor configuration and motor control for improved clarity and efficiency
    - Updated SliderConfig structure to unify speed representation in milliseconds.
    - Reduced maximum program count from 10 to 5 to fit within EEPROM constraints.
    - Simplified speed conversion logic by removing speed unit handling.
    - Refactored motor control functions to use milliseconds directly for speed.
    - Enhanced loop and complex program handling with binary data transmission.
    - Updated web interface to reflect changes in speed input and program management.
    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
2025-09-06 refactor(command): modularize command processing and simplify config handling
    - Removed configuration commands and related config management functionality
    - Added new bulk EEPROM loading command for efficient program data transfer
    - Simplified program management by embedding speed settings inside programs
    - Refactored command processing to handle binary commands centrally with command codes
    - Reduced EEPROM footprint by limiting max programs and storing
2025-09-06 refactor(config): remove complex program support, keep only loop programs
    - Simplify Config Manager to handle only loop program storage in EEPROM
    - Remove Complex program data structures and related functions from config_manager
    - Update program type enum to support only loop program type
    - Adjust processCommandCode to handle only loop programs, print error otherwise
    - Modify bulk EEPROM data handling to send and receive only loop programs
    - Remove legacy save/load complex program code from motor control and config_manager
    - Update motor_control to run only loop programs; remove runProgram for complex types
    - Refactor WebUSB script to support loop programs exclusively
    - Remove UI and storage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
    [motor_control.cpp]
2025-09-06 fix(command_processor): remove redundant displayMessage call in processCommandCode
    - Deleted unnecessary displayMessage invocation before switch statement
    - Improved code clarity and efficiency in command processing function
2025-09-06 refactor(command_processor): clean command codes and enhance unknown cmd handling
    - Removed commented out obsolete command codes for clarity
    - Added CMD_GET_ALL_DATA and CMD_DEBUG_INFO command codes
    - Improved unknown command handling by printing newline to Serial
    - Simplified enum for memory efficiency and maintainability
2025-09-06 refactor(display): update display with dynamic position parameter
    - Modify updateDisplay function to accept a position argument with default currentPosition
    - Print position parameter on display instead of fixed currentPosition variable
    - Add newline characters after status text (PAUSE, RUN, STOP) for clearer formatting
    - Call updated display function during motor movement to show current step position in real time
    [motor_control.cpp]
2025-09-06 feat(webusb): add manual movement velocity control with disconnection detection
    - Introduce velocity input control in WebUI for manual movement speed adjustment
    - Implement CMD_POS_WITH_SPEED and CMD_HOME_WITH_SPEED commands supporting custom speeds
    - Add input validation and persistence for manual speed using localStorage
    - Enhance Arduino firmware to handle new commands and move with specified speeds
    - Implement WebUSB disconnection detection with Arduino timeout and JavaScript event handling
    - Add periodic connection health check via CMD_DEBUG_INFO ping command
    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
2025-09-06 feat(display): add overloaded displayMessage function for regular strings
    - Implement displayMessage overload accepting String type messages
    - Clear display and set cursor before printing String message
    - Include optional duration delay and display update
    - Update header with new function declaration for String messages
2025-09-06 refactor(command): remove unused EEPROM data load command and related UI elements
    - Removed CMD_GET_ALL_DATA command from command_processor enum and logic
    - Deleted associated serial debug prints and processing code paths
    - Removed processCommand function and related calls to simplify command handling
    - Deleted "Load All from EEPROM" and "Clear Steps" buttons from web UI
    - Removed event listener and command code for requesting EEPROM data from webusb script
    - Cleaned up serial debug prints related to program execution and saving steps
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2025-09-06 fix(motor_control): call checkButton during motor movement and remove redundant delay code
    - Added checkButton() call inside moveToPositionWithSpeed to poll button state during movement
    - Removed obsolete cycling program delay logic in executeStoredProgram to simplify code flow
    - Retained error handling and idle delay behavior unchanged
    [motor_control.cpp]
2025-09-06 style(menu): reformat code for better readability and consistent indentation
    - Condensed single-line function definition for setupButton
    - Broke long if-condition into multiple lines in checkButton
    - Wrapped long function call arguments to multiple lines in buildMenuItems
    - Adjusted case statement indentations and spacing in selectMenuItem
    - Reordered statements in selectPauseMenuItem for logical flow
    - Ensured consistent usage of braces and spacing across functions
2025-09-06 fix(command): improve move command feedback and run status
    - Change display output to print move command with position and speed details
    - Set programRunning flag to true when move command is processed
    - Remove check for negative position in UI script input validation to allow zero or positive values
    - Clean up config_manager.h by removing obsolete default motor settings and comments
    - Adjust LoopProgram struct to indicate infinite running until stopped without cycles count
2025-09-06 refactor(motor_control): replace blocking delays with yieldingDelay function
    - Introduce yieldingDelay to split long delays into chunks and allow task responsiveness
    - Replace delay calls in moveToPositionWithSpeed with yieldingDelay for better multitasking
    - Use yieldingDelay in runLoopProgram and executeStoredProgram to improve responsiveness while paused or idling
    - Reduce updateDisplay frequency during motor movement to reduce overhead
    - Add yieldingDelay declaration to motor_control.h header for interface consistency
    [motor_control.cpp, motor_control.h]
2025-09-06 refactor(motor_control): replace fixed yield with callback-based yielding delay
    - Introduce YieldCallback function pointer type for flexible yield handling
    - Add setYieldCallback() to register yield callback functions dynamically
    - Modify yieldingDelay() to invoke registered callback during delays
    - Replace direct checkButton() calls with yield callback invocation
    - Update motor control header to declare new callback functions
    - Set checkButton() as yield callback in setup for modular design
    [motor_control.cpp, motor_control.h, steppper.ino]
2025-09-06 feat(kicad): add complete Dolly driver PCB layout and Gerber job file
    - Create Dolly driver kicad_pcb file with detailed footprints and layers setup
    - Define stackup layers with thicknesses and materials including dielectric and copper
    - Add multiple footprints including connectors, switches, and capacitors
    - Configure nets and pin connections for components on the PCB
    - Create Dolly driver driver-job.gbrjob with file attributes and material stackup
    - Specify Gerber job file parameters for outputting PCB manufacturing files
    [Dolly driver.kicad_pcb, Dolly driver.kicad_sch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]
2025-09-11 fix(kicad): correct net numbering and update pad connections in Dolly driver PCB
    - Renumber nets for consistency and correct sequencing
    - Update pad net assignments to reflect new net numbers
    - Adjust thermal bridge width and gap for enable pad
    - Remove redundant pinfunction and pintype entries
    - Ensure GND and VMOT net references are aligned correctly
    - Correct pinfunction and pintype assignments for clarity
    - Remove unconnected net labels and rename to proper nets where applicable
    - Fix net indices in segment and drill definitions for accuracy
    [Dolly driver.kicad_pcb, Dolly driver.kicad_sch]
2025-09-12 fix(config): update default microstepping and display menu behaviour
    - Change default microstepping value from 1 to 8 due to motor settings update
    - Modify display menu to show "Programs:" label instead of current selection arrow
    - Adjust program listing format by printing index, total count, and program name on same line
    - Replace exitMenuMode call with enterMenuMode after showing current position and delay
    - Update motor control display refresh to divide step count by new default microstepping value to reduce overhead
    [motor_control.cpp]
2025-09-12 chore(kicad): update .gitignore and fix step file path
    - Added kicad backup and lock files to .gitignore
    - Removed old lock files from repository
    - Corrected step file path in kicad project configuration file

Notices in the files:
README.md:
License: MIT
